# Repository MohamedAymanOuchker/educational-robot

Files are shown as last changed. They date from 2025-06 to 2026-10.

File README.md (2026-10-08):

# Educational Robot

> **P1 development revision:** the app/firmware control path now targets the confirmed 28BYJ-48 + ULN2003 build. Use the [new wiring](hardware/wiring.md) and matching app/firmware together. Hardware validation, printable exports and research reconciliation remain open; see [P1 status and test results](docs/p1-status.md).

> **P2 update:** named local Save/Open, execution-based practice progress, Bluetooth-only connection controls and a matching five-level curriculum are implemented. See [P2 status, tests and remaining work](docs/p2-status.md).

> **Android packaging:** the selected release ID, upgraded build tools and private-signing workflow are documented in the [release guide](docs/android-release.md). Debug packages are labeled RoboCode (Test); physical acceptance and a signed distribution release remain open.

> **Physical build handoff:** use the corrected [assembly guide](docs/assembly-guide.md), [blank acceptance record](docs/hardware-acceptance.md) and [CAD inventory/export checklist](hardware/cad-release.md). CAD inspection awaits the owner's CATIA installation; no physical tests or exports are claimed complete.

An affordable educational robotics platform designed to teach programming concepts to children aged 7-12 through hands-on interaction with a physical robot (developed as part of my engineering final year project internship).

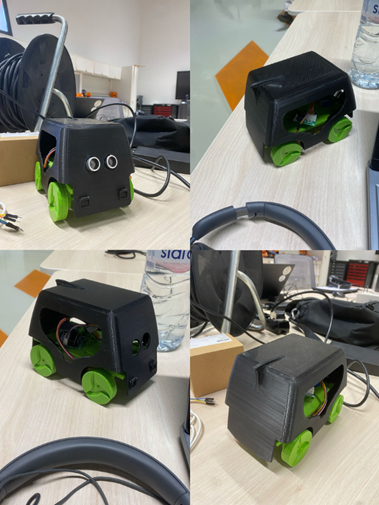
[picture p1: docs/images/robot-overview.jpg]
Robot Image







## 🎯 Project Overview

This prototype explores an affordable way to teach programming with a physical robot. The selected protected battery, regulator and external charger exceed the historical $40 parts estimate; see the [current parts selection and cost snapshot](hardware/power-system.md). A complete delivered build cost and comparative learning outcomes have not yet been established. The system combines:

- **ESP32-based hardware** with stepper motors and sensors
- **Flutter mobile app** with visual block programming
- **Progressive learning system** from basic commands to autonomous navigation
- **Real-time telemetry** for immediate feedback

## ✨ Key Features

- 📱 **Mobile-first design** - Flutter app with Android as the current build target
- 💰 **Cost-conscious design** - Documented parts selection; complete delivered costing pending
- 🎮 **Visual programming** - Custom block-based interface
- 🤖 **Auto Navigate** - Experimental three-second reactive activity
- 📊 **Real-time feedback** - Live sensor data visualization
- 💾 **Local programs** - Save/Open on the device; robot control uses Bluetooth
- 🔓 **Open source** - MIT license for educational use

## 🚀 Quick Start

### Prerequisites
- ESP32 development board
- 3D printer for chassis parts
- Compatible Android device with Bluetooth Low Energy for programming
- Basic soldering skills

### Hardware Assembly
1. Review the native CAD in `hardware/`; printable STL exports are still pending and `hardware/3d-models/` is not yet supplied
2. Follow the [Assembly Guide](docs/assembly-guide.md)
3. Use the [selected motor/power parts](hardware/power-system.md) and [revised ULN2003 wiring](hardware/wiring.md), then build/upload the modular firmware using PlatformIO

### Software Setup
1. Build the matching Android app from `mobile-app/` (see development instructions below)
2. Connect to the robot using the app's Bluetooth screen
3. Start with Level 1 programming challenges

## 📚 Documentation

- [**Assembly Guide**](docs/assembly-guide.md) - Step-by-step hardware build
- [**User Manual**](docs/user-manual.md) - How to use the system
- [**Curriculum Guide**](docs/curriculum-guide.md) - Educational activities
- [**Research & Evaluation**](docs/research-documentation.md) - Study results

## 🏗️ Project Structure

```
├── hardware/          # Native CATIA files and wiring guide; STL exports pending
├── firmware/          # ESP32 Arduino code (PlatformIO)
├── mobile-app/        # Flutter application
├── docs/              # All documentation, guides, and research
└── .github/           # CI/CD workflows
```

## 📋 Selected Bill of Materials

| Component | Quantity | Reference selection |
|---|---|---|
| ESP32 controller | 1 | ESP32-DevKitC V4 with WROOM module; verify any existing alternative board |
| 5 V motor + ULN2003 board | 2 kits | Olimex SM-5VDC-DRV, nominal 1:64 |
| Protected Li-ion battery | 1 | Tenergy 31003, 7.4 V / 2200 mAh |
| Fixed 5 V regulator | 1 | Pololu D24V22F5, item 2858 |
| External charger | 1 | Tenergy TLP-4000, item 01281 |
| HC-SR04 / MPU6050 | 1 each | Echo divider and 3.3 V-compatible IMU module |
| Power harness and protection | 1 set | DC fuse/switch, keyed connectors, insulated wiring and capacitors |
| Sensing dividers | 2 pairs | 2.2k/3.3k Echo; 20k/10k battery, 1% |
| Chassis, wheels and mounting hardware | 1 set | CAD/print fit and mechanical dimensions still require verification |

The [power-system specification](hardware/power-system.md) is the source for purchase links, ratings, the current budget and charging procedure. The four selected motor/power lines total **USD 67.43 plus EUR 5.00**, excluding the rest of this table, fabrication, tax and shipping. No complete-build price or measured runtime is claimed.

## 🎓 Educational Impact

The project documentation reports a pilot with 24 students aged 7-12. The author confirms that the study is real, but the aggregate results, session statistics and delayed follow-up claims require reconciliation against the original records. See [Research & Evaluation](docs/research-documentation.md) and the [reconciliation checklist](docs/research-reconciliation.md) before citing results. App progress indicators are not evidence of educational effectiveness.

## 🛠️ Development

### Building the Firmware
```bash
cd firmware/
# Using PlatformIO
pio run --target upload

# firmware/legacy is historical; it does not contain the current motor/safety fixes.
```

### Building the Mobile App
```bash
cd mobile-app/
# Tested toolchain: Flutter 3.41.4 / Dart 3.11.1
flutter pub get
flutter run
# To produce a local Android test package:
flutter build apk --debug
```

## 🤝 Contributing

We welcome contributions! Please see [CONTRIBUTING.md](CONTRIBUTING.md) for guidelines.

### Areas for Contribution
- [ ] iOS app development
- [ ] Additional language translations
- [ ] Curriculum expansion
- [ ] Hardware improvements
- [ ] Bug fixes and optimizations

## 📊 Performance Benchmarks

The following are historical reported figures. They have not been remeasured with this P1 motor/protocol revision and are not acceptance results for the updated code.

- **Movement Accuracy**: ±2cm per meter
- **Battery Life**: ~90 minutes continuous use
- **BLE Range**: 12+ meters
- **Command Latency**: <100ms
- **Setup Time**: 30 minutes average

## 🌍 Localization

The current app interface is English. Arabic localization is not implemented or validated in this build; translations into Arabic, French, Spanish and Portuguese are future contributions.

## 📄 License

This project is licensed under the MIT License - see the [LICENSE](LICENSE) file for details.

## 🙏 Acknowledgments

- **Euromed University of Fes** - Academic supervision
- **DICE/UM6P** - Host organization and support
- **Open source community** - Libraries and inspiration
- **Test participants** - Students and educators who provided feedback

## 📞 Contact

- **Author**: Mohamed Ayman OUCHKER
- **Email**: ayman.ouchker@outlook.com
- **Institution**: Euromed University of Fes
- **Project**: End of Studies Project 2024-2025

## 🌟 Star History

If this project helps you, please consider giving it a star! ⭐

---

**Made with ❤️ for democratizing robotics education**

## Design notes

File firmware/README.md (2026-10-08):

# E-Bug ESP32 firmware

The supported firmware is `src/`, built with PlatformIO for an ESP32 Dev Module. It controls two **28BYJ-48 motors through ULN2003 boards**. The archived `legacy/arduino_main/` sketch is historical reference and is not a supported firmware option for this release.

## Wiring and calibration

The old STEP/DIR wiring does not apply. Rewire each ULN2003 board in its marked IN1–IN4 order:

| Connection | ESP32 GPIOs |
|---|---|
| Left ULN2003 IN1, IN2, IN3, IN4 | 26, 27, 25, 33 |
| Right ULN2003 IN1, IN2, IN3, IN4 | 14, 13, 32, 23 |
| HC-SR04 trigger, echo | 5, 18 |
| MPU6050 SDA, SCL | 21, 22 |
| Battery divider ADC input | 35 |

See [the wiring guide](../hardware/wiring.md) and [selected motor/power parts](../hardware/power-system.md) before applying power. The reference design uses 5 V motors, a protected 2S Li-ion pack and a fixed 5 V regulator. Check existing parts against that selection. Share logic ground; reduce the HC-SR04 Echo voltage and verify the battery divider before connecting the ESP32. Firmware cannot select or verify the motor's physical voltage rating.

The driver uses an eight-phase half-step sequence, nominal **4096 half-steps per output revolution**, and **2000 microseconds per half-step** (500 half-steps/s, subject to RTOS scheduling). Gearbox variants differ: calibrate steps/revolution, the retained 65mm wheel diameter and 150mm track width against the actual robot. These geometry values are assumptions, not measured results.

The [physical acceptance record](../docs/hardware-acceptance.md#motion-calibration) provides calibration formulas and trial tables, including external gearing. Use the [assembly sequence](../docs/assembly-guide.md) to keep USB programming separate from powered motor tests. No runtime calibration command replaces those measurements.

`LEFT_MOTOR_INVERT=false` and `RIGHT_MOTOR_INVERT=true` assume mirrored mounting. Check forward, backward and both turns with wheels raised, and adjust these constants to match the wiring/mounting. Motors start deenergized and release their coils after each movement. STOP deenergizes all eight outputs and stays latched until a new explicit command is accepted. Old stored motor-speed settings are not loaded.

## Build, test and upload

Install PlatformIO Core, then run from this folder:

```sh
pio run
python test/host/run_tests.py
```

The host tests require Python and a C++17 compiler (`g++` or `clang++`, or set `CXX`). They compile the production source with hardware/FreeRTOS/BLE doubles. They check parsing, coils, cancellation races, queue capacity, sensor failures/freshness and navigation thresholds. They do not validate motor torque, actual radio delivery, power integrity or physical stopping distance.

The reproducible build pins Espressif32 7.0.1, ArduinoJson 6.21.6 and MPU6050 1.4.5. Only upload after checking the wiring and motor voltage:

```sh
pio run --target upload
pio device monitor
```

Serial monitoring uses 115200 baud. Board flashing is not part of the automated checks.

## BLE commands and results

The complete app/firmware contract is in [BLE protocol](../docs/ble-protocol.md). UUIDs remain unchanged. Send one ASCII command in one GATT write, with a request ID from 1 through 65535 and a trailing newline:

```text
1:F20
2:L90
3:STOP
```

| Command | Meaning |
|---|---|
| `F0` through `F500` | Forward distance in centimetres |
| `B0` through `B500` | Backward distance in centimetres |
| `L0` through `L360`, `R0` through `R360` | Turn angle in degrees |
| `STOP`, `AUTO_OFF` | Priority stop, cancel queue and leave autonomous mode |
| `AUTO_NAV` | Enable autonomous mode; completion confirms mode activation |
| `CLOOP_OFF` | Confirm the supported open-loop turning mode |
| `CALIBRATE`, `CLOOP_ON` | Explicit error: unavailable in this release |

Unnumbered commands are accepted for manual diagnostics and return ID 0. Runtime recalibration and closed-loop turns are not enabled. Initial IMU calibration may still run at boot if no calibration is stored; keep the robot still during startup.

Unknown commands, negative/fractional values, overflow, trailing garbage and overlong writes are rejected. They never become STOP or a clamped movement. Queue-full requests return errors. STOP bypasses the queue, cancels pending commands and prevents previously dequeued commands from rearming motion. Disconnection performs the same physical stop and queue cancellation; results cannot be delivered while disconnected.

All responses are newline-delimited JSON on the sensor notification characteristic. Records are split into chunks of at most 20 bytes; clients must buffer until newline. Complete records are serialized under a mutex so telemetry and command responses cannot interleave.

```json
{"type":"command","id":1,"status":"done"}
{"type":"command","id":2,"status":"cancelled","message":"stopped during command"}
{"type":"telemetry","distance":null,"distance_valid":false,"distance_age_ms":320,"battery":80,"heading":0,"temperature":25,"timestamp":10200}
```

An autonomous safety abort also emits `{"type":"fault","message":"..."}` so the app fails the active program even after mode activation was acknowledged. A user STOP alone does not emit a fault.

A blocked/aborted movement returns `error`/`cancelled`, never `done`. A failed movement also cancels the remaining queued program. `AUTO_NAV` runs until STOP/AUTO_OFF, disconnect or a sensing failure; the mobile app bounds its autonomous block to three seconds and then sends STOP.

## Sensing and remaining hardware checks

Ultrasonic sampling is scheduled every 60ms, with trigger spacing shared by all callers. No echo or out-of-range echo immediately invalidates the range. A successful sample older than 250ms is also invalid. Forward motion checks this coherent sensor snapshot at every half-step; missing/stale distance or a reading below 15cm stops the movement. Invalid range is reported as JSON `null`, never a false-clear 999cm value.

The sensor task services IMU integration nominally every 10ms (ultrasonic echo waits can delay it). Telemetry is sent separately every 250ms. Heading is an uncorrected gyro estimate and may drift; MPU6050 temperature is die temperature. Battery percentage depends on the configured pack/divider calibration.

Autonomous forward steps cover the previous 25–50cm dead zone. Invalid range or critically close obstacles stop autonomous operation. The existing turning/scanning heuristic remains experimental. There is no rear/side sensor: supervise backward movement and rotations. Bench validation must still establish motor direction, distance/angle calibration, reliable BLE stop/disconnect behavior, voltage levels, and stopping clearance on the actual robot.

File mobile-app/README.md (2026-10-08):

# RoboCode Mobile App

A Flutter-based mobile application for programming and controlling educational robots using visual block-based coding. This app is part of the Educational Robot project, designed to make robotics and programming accessible to learners.

The P1 revision requires the matching [firmware protocol](../docs/ble-protocol.md) and [28BYJ-48 / ULN2003 wiring](../hardware/wiring.md). Android is the current build target; iOS support and store releases are not validated.

## Features

- 🎯 Visual Block-Based Programming Interface
- 🤖 Bluetooth connectivity with educational robots
- 💾 Named local Save/Open with nested block and parameter restoration
- ✅ Five practice checks based on successful execution, separate from saving
- 📱 User-friendly interface with multiple screens:
  - Home Screen: Main navigation and project overview
  - Connect Screen: Bluetooth scan, connection and disconnection
  - Code Screen: Block-based programming interface
  - Sensors Screen: Automatically pushed readings with unavailable/stale states
- Run opens Robot Execution from Code; there is no placeholder Run tab

## Technical Stack

- **Framework**: Flutter
- **State Management**: Provider
- **Key Dependencies**:
  - `flutter_blue_plus`: Bluetooth communication
  - `flutter_inappwebview`: Web-based components
  - `provider`: State management
  - `shared_preferences`: Local data storage
  - `google_fonts`: Typography
  - `lottie`: Animations

## Getting Started

### Prerequisites

- Flutter 3.41.4 / Dart 3.11.1 (the validation and CI toolchain)
- Android SDK and a compatible Java installation (CI uses Java 17)
- Android device with Bluetooth Low Energy and the matching updated ESP32 firmware

Android packaging uses Gradle 8.14, Android Gradle Plugin 8.11.1 and Kotlin 2.2.20. See the [Android release guide](../docs/android-release.md) for the selected application ID, separate test installation, private signing setup and unsigned CI build checks. Normal release builds require an owner-provided key; debug signing is never used as a release fallback.

### Installation

1. Open the cloned project's app directory:
   ```bash
   cd educational-robot/mobile-app
   ```

2. Install dependencies:
   ```bash
   flutter pub get
   ```

3. Run the app:
   ```bash
   flutter run
   ```

### Development

Run the regression checks and create an Android test package:

```bash
flutter analyze --no-fatal-infos
flutter test
flutter build apk --debug
```

The tests cover protocol framing/completion, typed program execution and block editor behavior. Hardware connection, motor direction, stop latency and sensor behavior still require an actual robot. See [P1 status](../docs/p1-status.md) for validation results and open items.

Programs execute the edited block tree and wait for firmware completion records. Generated Dart is a preview only. If Distance uses fresh valid telemetry; its children are skipped when false. Auto Navigate runs for three seconds and stops. Leaving the execution screen or backgrounding the app cancels the run and requests STOP.

Use **Save** and **Open** in Code for a local library (up to 50 programs, 100 blocks each). Names are case-insensitive; replacement and clearing require confirmation. Unsaved edits survive tab switches, but must be saved before closing the app. No file export or cloud backup is implemented.

The connection UI supports **Bluetooth Low Energy only**. Scans filter for the robot service, report permission/adapter errors, stop after about ten seconds and cancel their native scan when the screen's subscription ends. The unused Wi-Fi UI, password form, service stubs, plugin and Wi-Fi permissions have been removed. Android permission behavior still needs physical-device testing.

The editor now reads a typed list of implemented blocks for each lesson. Home and Code use the same lesson names/descriptions; the [current curriculum](../docs/curriculum-guide.md) teaches explicit movement sequences, Wait, one-sided distance decisions and bounded Auto Navigate. Repeat/While, If/Else, speed controls, mapping, localization and iOS release support are not implemented.

Sensors automatically displays new telemetry. It clears missing/invalid fields and expired/disconnected readings instead of showing default values or carrying old readings into a new packet. Distance freshness includes the firmware's reported age. Battery is an estimate; IMU temperature and relative heading are not a room thermometer or compass. No monitoring Start/Stop buttons or movement controls appear in Sensors.

Practice checks are based on executed nonzero actions, conditional responses and successful final STOP. Save never awards progress. Old badge data retains lesson access without counting as verified execution; cached robot connection flags are ignored. See [P2 status](../docs/p2-status.md) for the storage format, migration, checks and remaining work.

The app is structured into several key directories:

- `lib/screens/`: Main application screens
- `lib/services/`: Business logic and state management
- `lib/widgets/`: Reusable UI components
  - `block_editor/`: Custom widgets for the visual programming interface

## Contributing

Please read the CONTRIBUTING.md file in the root directory for details on our code of conduct and the process for submitting pull requests.

## License

This project is licensed under the terms found in the LICENSE file in the root directory.

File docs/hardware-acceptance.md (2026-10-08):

# Physical robot acceptance record

Blank template prepared 8 October 2026. **All tests are NOT RUN until the tester records observations.** No phone, serial controller or physical robot was available for this documentation pass. CATIA validation/exports are deferred until the owner installs it.

Copy this file for each robot and test session. Use PASS, FAIL, NOT RUN or NOT APPLICABLE with a reason. A blank value is missing evidence, not zero or a pass. Keep this engineering record separate from participant/study data.

## Build identity

| Field | Recorded value |
| --- | --- |
| Robot / build ID | Pending |
| Tester and date | Pending |
| Git commit plus description of uncommitted changes | Pending |
| Firmware binary path + SHA-256 | Pending |
| App package path + SHA-256 / application ID / version | Pending |
| Phone model + Android version | Pending |
| ESP32 board/module revision | Pending |
| Delivered motor / driver labels, photos and polarity | Pending |
| Battery / regulator / charger model + condition | Pending |
| Harness connector, fuse, switch and wire identification | Pending |
| CAD assembly/revision + source hashes + export record | Pending |
| Mechanical dimensions / external gearing | Pending |
| Surface, payload and ambient conditions | Pending |
| Meter / timing / temperature instruments and resolution | Pending |

Use `Get-FileHash -Algorithm SHA256 -LiteralPath 'exact-file-path'` in PowerShell to identify a tested binary. A Git commit alone does not identify uncommitted firmware/configuration changes. Preserve the actual package and configuration used for each test.

## Acceptance limits agreed before testing

The power targets below come from the [project power specification](../hardware/power-system.md); they are not measured results. Record the remaining limits before judging a test. A successful protocol response is not proof of physical travel or stopping.

| Quantity | Target / decision required |
| --- | --- |
| Regulated 5 V rail | 4.8–5.2 V at specified test inputs/load and actual operation |
| Regulator test inputs / load | 8.4 V and 6.4 V input, 1.2 A output design load; use appropriate bench equipment |
| Battery operating procedure | Stop/recharge at about 6.4 V under load; no automatic firmware cutoff |
| Echo divider expected DC ratio | 3.3 / (2.2 + 3.3) = 0.6; approximately 3.0 V at 5.0 V input |
| Battery divider expected DC ratio | 10 / (20 + 10) = 1/3; approximately 2.8 V at 8.4 V input |
| Accessible-surface/component temperature limits | Record applicable component limits and an appropriate supervised-use limit before testing: pending |
| Explicit STOP maximum latency / extra travel | Pending; define for the intended test area and activity |
| BLE-loss maximum latency / extra travel | Pending; include radio loss-detection time, not only code response time |
| Linear error / repeatability at chosen distances | Pending |
| Left/right angular error / repeatability | Pending |
| Sensor error / repeatability at intended target distances | Pending |
| Required phone range and environmental conditions | Pending; no 12 m guarantee |

Without an agreed limit and measurement, record the result as NOT RUN or measured-but-not-accepted. Do not treat the absence of a failure message as acceptance.

## A. Mechanical and electrical preflight

Follow the [assembly guide](assembly-guide.md) and [wiring](../hardware/wiring.md). Wiring changes happen with power disconnected. Do not attach USB while the battery/external ESP32 5 V feed is connected.

| ID | Check | Measurement / evidence | Result |
| --- | --- | --- | --- |
| A1 | Native assembly opens; references resolved; part-to-file mapping complete | Pending | NOT RUN |
| A2 | Motor mounting, shaft/hub retention, gear ratio, free rotation and cable clearance | Pending | NOT RUN |
| A3 | Battery retention/removal, insulated terminals, fuse/switch/connector access | Pending | NOT RUN |
| A4 | Disconnected continuity, no supply short, ground/polarity/capacitor checks | Pending | NOT RUN |
| A5 | USB/external 5 V separation and actual ESP32 board pinout | Pending | NOT RUN |
| A6 | 8.4 V input, regulator unloaded and at 1.2 A design load | Pending | NOT RUN |
| A7 | 6.4 V input, regulator unloaded and at 1.2 A design load | Pending | NOT RUN |
| A8 | Battery divider before connection to GPIO35 | Pending | NOT RUN |
| A9 | Echo divider ratio and signal peak before connection to GPIO18 | Pending | NOT RUN |
| A10 | Actual idle/start/motion current, rail transients, fuse behavior | Pending | NOT RUN |
| A11 | Regulator, motor, driver, wiring and accessible-surface temperatures; test duration | Pending | NOT RUN |
| A12 | Charger/pack/harness match and external charging procedure | Pending | NOT RUN |

A multimeter DC reading alone does not measure transient rail droop or the peak of an Echo pulse. Record the instrument and any unmeasured behavior. Do not deliberately short a battery, defeat its protection or discharge it to emergency cutoff as a test.

## B. Stationary sensing and raised-wheel commissioning

Keep the chassis secured, wheels clear, hands away and the disconnect reachable. Restore/check wiring with power off between fault configurations. Use the app's short test programs described in the assembly guide.

| ID | Test | Observation / evidence | Result |
| --- | --- | --- | --- |
| B1 | Startup, connecting and reconnecting cause no uncommanded movement | Pending | NOT RUN |
| B2 | Forward/backward wheel directions and left/right turns agree with commands | Pending | NOT RUN |
| B3 | Single motion waits for completion; coils release after motion | Pending | NOT RUN |
| B4 | Stable front readings with measured targets at intended distances | Pending | NOT RUN |
| B5 | No echo / disconnected Echo signal reports unavailable and prevents forward motion | Pending | NOT RUN |
| B6 | Sensor fault during controlled forward motion stops/fails the action | Pending | NOT RUN |
| B7 | Battery estimate compared with meter; IMU temperature/relative heading interpreted correctly | Pending | NOT RUN |
| B8 | Physical disconnect stops powered drive; record any coasting | Pending | NOT RUN |

For B6, first agree a fault method that does not short or change energized wiring (for example a preinstalled insulated signal switch, or controlled loss of a valid acoustic target). Record the method and raw observation; do not label an arbitrary “far away” reading a guaranteed fault.

### Stop and cancellation observations

Begin with the wheels raised. Repeat relevant cases during short, controlled floor motion only after raised-wheel tests pass. Use video/timing equipment where needed. Record multiple trials, the maximum observed latency, extra wheel/chassis travel, and the app outcome. The reference point is the user action or fault onset, not receipt of a later log line.

| Trigger | Trials / conditions | Maximum measured latency | Extra travel / residual motion | App outcome; no restart on reconnect | Result |
| --- | --- | --- | --- | --- | --- |
| Whole-run Stop during a forward action | Pending | Pending | Pending | Pending | NOT RUN |
| Whole-run Stop during a turn | Pending | Pending | Pending | Pending | NOT RUN |
| Leave Robot Execution | Pending | Pending | Pending | Pending | NOT RUN |
| Background / lock phone | Pending | Pending | Pending | Pending | NOT RUN |
| Disconnect in Connect | Pending | Pending | Pending | Pending | NOT RUN |
| Disable phone Bluetooth / actual radio loss | Pending | Pending | Pending | Pending | NOT RUN |
| Ultrasonic invalid/stale condition during forward motion | Pending | Pending | Pending | Pending | NOT RUN |
| Auto Navigate timeout / fault | Pending | Pending | Pending | Pending | NOT RUN |

Differentiate a confirmed STOP, cancelled program, failed/unconfirmed STOP and disconnected robot. A UI status alone does not establish that physical motion ceased. Rear/side collision protection is not implemented.

## Motion calibration

Do this only after mechanical, power, sensor and stop checks pass. Constants are in `firmware/src/config.h`. The production formulas in `firmware/src/motor_control.cpp` are:

```text
linear half-steps = round(command_cm × 10 × STEPS_PER_REV / (pi × WHEEL_DIAMETER))
turn half-steps per wheel = round(ROBOT_WIDTH × abs(command_degrees) × STEPS_PER_REV
                                 / (360 × WHEEL_DIAMETER))
```

`STEPS_PER_REV` must represent effective half-steps per **wheel** revolution. If external gears exist, multiply motor-output half-steps/revolution by motor-output revolutions per wheel revolution. Verify tooth counts and physical motion; the nominal internal-gear value 4096 is not a measurement.

Record mechanical wheel diameter and centre-to-centre track width first. Resolve slipping, binding or missed steps before numerical correction. Repeat the same motion on the same surface and load; retain every trial, including failed/cancelled ones. Exclude failed motion from parameter fitting with a recorded reason.

| Trial | Command / direction | Actual distance (cm) or angle (degrees) | Surface / load / pack voltage | Completion / slip / notes |
| --- | --- | --- | --- | --- |
| 1 | Pending | Pending | Pending | Pending |
| 2 | Pending | Pending | Pending | Pending |
| 3 | Pending | Pending | Pending | Pending |
| 4 | Pending | Pending | Pending | Pending |
| 5 | Pending | Pending | Pending | Pending |

Copy the table for each distance and turn direction. Begin with 20 cm travel and 45° turns; increase to a longer baseline/90° only when clearance and the preceding checks permit.

For stable, nonzero travel measurements, adjust **one** linear parameter, not both at once:

```text
STEPS_PER_REV_new = STEPS_PER_REV_old × commanded_distance / mean_measured_distance
```

Alternatively, with independently established steps/revolution, use an effective rolling diameter:

```text
WHEEL_DIAMETER_new = WHEEL_DIAMETER_old × mean_measured_distance / commanded_distance
```

After linear calibration, an effective turn-track correction is:

```text
ROBOT_WIDTH_new = ROBOT_WIDTH_old × requested_turn_magnitude / mean_measured_turn_magnitude
```

These formulas follow the open-loop implementation; they are not measured results. Keep physical dimensions and fitted effective parameters separately identified. Round `STEPS_PER_REV` to a suitable integer. Do not average away a left/right discrepancy: inspect mechanics and record each direction's residual error. Rebuild/reflash and repeat tests after changes. Significant gearing/speed changes also require checking the app's command deadlines; a timeout must not be relabeled as successful completion.

| Parameter | Before | Measured basis / calculation | After | Retest evidence |
| --- | --- | --- | --- | --- |
| Effective half-steps / wheel revolution | Pending | Pending | Pending | Pending |
| Physical / effective wheel diameter (mm) | Pending | Pending | Pending | Pending |
| Physical / effective track width (mm) | Pending | Pending | Pending | Pending |
| Left/right inversion and step interval | Pending | Pending | Pending | Pending |

## C. Physical phone and lesson checks

| ID | Test | Phone / conditions / evidence | Result |
| --- | --- | --- | --- |
| C1 | First-run permission grant/denial/retry; Bluetooth off/on | Pending | NOT RUN |
| C2 | Scan finds the correct robot; stop/timeout/cancel; no late background scan | Pending | NOT RUN |
| C3 | Connect/reconnect after backgrounding and radio loss | Pending | NOT RUN |
| C4 | Sensors reflect fresh data; stale/missing/disconnected readings become Unavailable | Pending | NOT RUN |
| C5 | Short movement/Wait/nested true and false distance programs | Pending | NOT RUN |
| C6 | Save, app restart, Open, edit and supervised Run; no false practice badge | Pending | NOT RUN |
| C7 | False/invalid distance condition and aborted run report the right outcome | Pending | NOT RUN |
| C8 | Three-second Auto Navigate: actual trajectory, final heading, timeout/fault and stop behavior | Pending | NOT RUN |
| C9 | Portrait layout, large text, keyboard and system Back on intended phones | Pending | NOT RUN |
| C10 | Measured connection time/range with stated environment and radio-loss response | Pending | NOT RUN |

Auto Navigate may stop during a scan/turn; it does not promise a completed route or return to its original heading. Sensor validity is not clearance behind or beside the robot. A successful practice badge is not a study outcome.

## Decision and unresolved work

| Field | Recorded value |
| --- | --- |
| Failed / unmeasured items and corrective actions | Pending |
| Retest references after fixes | Pending |
| Permitted supervised activity and operating limits | Pending |
| Reviewer / date | Pending |
| Overall decision | NOT ACCEPTED — template is unfilled |

Do not convert NOT RUN to PASS to close the project. Keep native/exported CAD evidence, physical test evidence, Android signing/distribution and [research reconciliation](research-reconciliation.md) as separate deliverables. None is established by filling in another.

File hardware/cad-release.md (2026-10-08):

# CAD inventory and mechanical release

Status on 8 October 2026: **native files inventoried; geometry and assembly references not validated; no printable or neutral exports supplied**. The owner will install CATIA later. Native files have been preserved without renaming or deletion.

## What is present

[cad-inventory.json](cad-inventory.json) records exact relative paths, file sizes and SHA-256 hashes for **10 CATPart files and 4 CATProduct files**. Hashes identify these file versions; they do not verify dimensions, manufacturability or assembly completeness.

| Native file | Bytes | Role in the robot |
| --- | ---: | --- |
| `jh.CATPart` | 553637 | Unverified |
| `Part1.CATPart` | 367475 | Unverified |
| `Part2.CATPart` | 171317 | Unverified |
| `Part3 (1).CATPart` | 83476 | Unverified; byte-identical to Part3 |
| `Part3.CATPart` | 83476 | Unverified; byte-identical to Part3 (1) |
| `Part4.CATPart` | 194926 | Unverified |
| `Part6.CATPart` | 227954 | Unverified |
| `StepperMotor.CATPart` | 78186 | Name suggests a motor model; compatibility with delivered motor unverified |
| `Zoo Text-to-CAD_1.CATPart` | 343300 | Unverified |
| `Zoo Text-to-CAD_2.CATPart` | 321603 | Unverified |
| `Product1 1.CATProduct` | 80326 | Candidate assembly; hierarchy unverified |
| `Product1.CATProduct` | 79714 | Candidate assembly; hierarchy unverified |
| `Product3.CATProduct` | 28491 | Candidate assembly; hierarchy unverified |
| `miter-gear-and-driver-gear-to-drive-it-make-the-driver-gear-one-half-size-of-the-miter-gear (1).CATProduct` | 15896 | Name suggests gears; actual ratio and placement unverified |

Do not delete either Part3 copy until CATIA shows which paths the assemblies reference. File identity does not establish that either filename is unused. Likewise, similar product names do not establish which assembly is final. A filename describing a gear ratio is not a dimensional measurement.

## Work to complete when CATIA is available

1. Open each candidate CATProduct from this folder. Record the CATIA version, missing references, load/update warnings and resolved child paths. Select the actual top-level robot assembly using its contents and the intended physical build.
2. Identify each printable part and each purchased/reference component. Record quantities, mirrored variants, suppressed components and dependencies. Map descriptive part names to existing files before considering native-file renames.
3. Verify dimensions in millimetres: delivered motor mounting and shaft profile, wheel/hub fit, external gear tooth counts and alignment, battery retention/removal, PCB mounting, switch access, wire clearance and sensor sight line. Use [selected parts](power-system.md), with actual measurements taking precedence over provisional envelopes.
4. Check clashes, fastener engagement, wall thickness, free wheel/gear motion and assembly access. Record tolerances and intended fabrication method. Do not infer clearances from screenshots.
5. Export the verified printable parts to STL and suitable neutral geometry to STEP. Record units, source revision, export settings and part quantity. These formats are deliverables to create, not files already present.
6. Reopen exports in an independent viewer/slicer. Confirm scale against a known measured feature, dimensions, orientation and mesh suitability. Slice a critical fit piece first and record the printer/material/settings and result.
7. Supply an assembly drawing or annotated views showing how part names, fasteners and electrical components correspond to the actual design. Complete the mapping below and update the inventory for intentionally revised native files, retaining the prior inventory with the build evidence.

## Part-to-file and export record

The names below describe functions to identify. They do not assert that a matching part exists in the current assembly. Add or remove rows after inspecting the real design.

| Function | Native source + assembly instance | Quantity | Measured critical dimensions / fit | STL / STEP / drawing paths | Verification evidence |
| --- | --- | --- | --- | --- | --- |
| Chassis / structural base | Pending | Pending | Pending | Not supplied | Not checked |
| Motor mounts | Pending | Pending | Delivered mounting holes and shaft access | Not supplied | Not checked |
| Wheel hubs / wheels | Pending | Pending | Shaft profile, diameter, retention | Not supplied | Not checked |
| External gears, if actually used | Pending | Pending | Tooth counts, ratio, alignment | Not supplied | Not checked |
| Battery holder / retention | Pending | Pending | Delivered pack + harness/removal clearance | Not supplied | Not checked |
| Ultrasonic / IMU mount | Pending | Pending | Sensor orientation and sight line | Not supplied | Not checked |
| Electronics mounting / cover, if used | Pending | Pending | PCB spacing, access, insulation | Not supplied | Not checked |

For each export, keep its hash and the native source hash from the inventory. Record any repair or unit conversion. A successful export alone is not a passed physical fit test.

Continue with the [assembly guide](../docs/assembly-guide.md) and [hardware acceptance record](../docs/hardware-acceptance.md) once the necessary geometry and parts are ready.

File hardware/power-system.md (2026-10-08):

# Selected motor and power system

Design selection: 8 October 2026. The owner authorized choosing a complete compatible setup. These are the parts to build toward; online research does not identify the parts already installed. The assembly still needs inspection and bench testing.

## Selected parts

| Item | Qty | Selected part | Reason / specification |
|---|---:|---|---|
| Motor and driver | 2 | [Olimex SM-5VDC-DRV](https://www.olimex.com/Products/Robot-CNC-Parts/StepperMotors/SM-5VDC-DRV/) | 5 V 28BYJ-48, nominal 1:64 gearing, ULN2003 board; matches the current four-input-per-motor firmware |
| Battery | 1 | [Tenergy 31003](https://power.tenergy.com/tenergy-li-ion-7-4v-2200mah-rechargeable-battery-w-pcb-2s1p-16-25wh-4a-rate/) | Factory-assembled, PCB-protected 2S1P Li-ion pack, 7.4 V nominal, 2200 mAh |
| Regulator | 1 | [Pololu D24V22F5, item 2858](https://www.pololu.com/product/2858) | Fixed 5 V buck regulator; manufacturer lists 2.5 A typical maximum at 24 V input, with actual capacity depending on input and cooling |
| External charger | 1 | [Tenergy TLP-4000, 01281](https://power.tenergy.com/tenergy-tlp-4000-universal-1a-smart-charger-for-li-ion-polymer-battery-pack-3-7v-14-8v-1-4-cell/) | 1 A CC/CV charger, explicitly listed by Tenergy for battery 31003; automatically recognizes supported cell counts |

Use two matching 5 V motors. Existing units may be retained only after their labels, wiring and gearing are checked. A ULN2003 board marked "5–12 V" does not change the attached motor's voltage rating. Do not apply the battery directly to the motor supply.

The chosen pack uses **8.4 V at full charge and 6.0 V as its specified discharge endpoint**. The existing firmware constants (8.4 / 6.0 V and a divide-by-three sensing network) already match those endpoints. The older [manufacturer specification, page 3](https://www.tenergy.com/core/media/media.nl/id.36145/c.671216/.f?h=384b24cc1d4ad2a6829c) confirms them. Battery percentage remains an approximate voltage-based indication, not protection or an automatic shutdown.

Source discrepancies are recorded instead of silently selecting the larger rating: the current battery page shows both 3 A and 4 A discharge figures, so use **3 A as the design ceiling**. The older sheet and current listing also differ on physical dimensions; measure the delivered pack before finalizing its holder.

## Additional assembly parts

These are project design choices, subject to the load and wiring checks below:

- **F1:** 2 A fast-acting fuse with a documented DC rating of at least 32 V, in an insulated holder close to the battery's positive output. Use a fuse/holder suitable for a lithium battery's possible fault current; the pack PCB does not replace it.
- **S1:** accessible on/off switch rated at least 3 A at 12 V DC. An AC-only switch rating is not sufficient evidence of its DC rating.
- **J1:** keyed, locking two-pin battery connector/harness rated at least 3 A at 12 V DC, with recessed battery-side contacts. Specify pin 1 as positive/red and pin 2 as negative/black on both the robot and charger adapter; verify polarity electrically.
- Short **20 AWG stranded copper** power leads, insulated joints, strain relief and a soldered/terminal-block distribution point. Keep motor current out of solderless breadboard rails and thin signal jumpers.
- **C1:** 470 microfarad, 16 V electrolytic across the 5 V distribution rail, observing polarity; 100 nF ceramic locally across each driver's supply.
- Echo divider: **2.2 kohm / 3.3 kohm, 1%**. Battery divider: **20 kohm / 10 kohm, 1%**. See the [GPIO wiring guide](wiring.md).
- Insulated regulator mounting, battery retention and a charger mains lead/plug suitable for the local socket. Do not open or modify mains-side equipment.

The standard battery is supplied with bare leads and the charger with clips: **the parts do not arrive as a plug-and-play harness**. Have the pack supplier or a competent assembler fit J1 and an insulated matching charger adapter. Work on the provided leads, never directly on the cells. Exposed clip connections are not the student operating interface.

## Power connections

```text
Tenergy 31003 protected pack
  P+ -- F1 (2 A) -- J1 pin 1 -- S1 --+-- Pololu VIN
                                   +-- 20k/10k divider -- GPIO35
  P- -------------- J1 pin 2 -------+-- common GND

Pololu VOUT (5 V) --+-- left ULN2003 motor supply
                   +-- right ULN2003 motor supply
                   +-- HC-SR04 VCC
                   +-- removable feed --> ESP32 board 5V input
                   +-- C1 positive; C1 negative --> GND

ESP32 board 3V3 ---------------------- MPU6050 supply (3.3 V-compatible module)
All board/driver/sensor grounds ------ common GND

Charging: unplug J1 from the robot and connect the fused pack harness
          to the matching TLP-4000 adapter instead. No simultaneous load.
```

Use the regulator's labeled **VIN, GND and VOUT**. Leave **EN and PG unconnected** in this design; EN has an onboard pull-up. Do not connect EN to an ESP32 GPIO directly. Its fixed output needs no potentiometer adjustment. The regulator's dropout, thermal and current limits must be verified at the actual load. [Pololu connection instructions](https://www.pololu.com/product/2858).

The controller reference is an **ESP32-DevKitC V4 with an ESP32-WROOM module**. Feed its 5V header, never a bare WROOM module's 3.3 V supply. Espressif requires choosing only one board power source. For USB programming, unplug the battery and remove the board's external 5 V feed so USB cannot backfeed the regulator/motor rail. Disconnect USB before restoring battery operation. An existing different ESP32 board needs its own pinout checked. [Espressif board power instructions](https://docs.espressif.com/projects/esp-dev-kits/en/latest/esp32/esp32-devkitc/user_guide.html).

## Current budget and operating limits

This is a **calculated design allowance**, not a measurement or battery-life claim:

| 5 V rail load | Allowance |
|---|---:|
| Both motors, up to two energized coils each | 0.45 A |
| ESP32 development board, including radio activity | 0.55 A |
| Sensors and driver indicator LEDs | 0.10 A |
| Reserve | 0.10 A |
| **Design test load** | **1.20 A / 6 W** |

The motor estimate uses the 50 ohm +/-10% winding example in [Waveshare's 28BYJ-48 documentation](https://files.waveshare.com/upload/f/f8/Motor_Control_Shield_User_Manual_EN.pdf): four active coils at 5 V / 45 ohm give approximately 0.44 A before driver losses. That is an assumption until the selected motors are measured. The controller allowance accounts for [Espressif's recommendation of at least 500 mA supply capability](https://docs.espressif.com/projects/esp-hardware-design-guidelines/en/latest/esp32/schematic-checklist.html), not a claim that the board continuously draws that current.

At 6.4 V input, 6 W output and an assumed 85% conversion efficiency, estimated battery current is `6 / (6.4 * 0.85) = 1.10 A`. This is below the conservative pack limit and leaves room below F1's nominal rating. Validate startup inrush and fuse suitability; do not increase the fuse simply to hide an unexplained trip.

For supervised use, stop and recharge at about **6.4 V under load**, before the specified 6.0 V endpoint. This is an operating target, not a firmware cutoff. Verify voltage with a meter while calibrating telemetry; do not intentionally run to the pack's emergency PCB cutoff. Keep the power switch off during storage. Actual runtime and loaded motor torque remain unmeasured.

## Charging procedure

1. An adult switches the robot off, unplugs J1 and removes the pack for charging. The fuse stays with the pack harness.
2. Check the pack and keyed adapter, then use the selected TLP-4000 according to its instructions. It accepts 100–240 V AC and charges this protected 2S pack at up to 1 A; charge indoors within the pack's permitted temperature range.
3. Charge attended, clear of combustible materials. Disconnect after the charger's completion indication. Reconnect to the robot only after removing the charger.

This charger is specified for **protected** Li-ion/LiPo packs; it is not a balance charger for unprotected hobby packs. Do not substitute a TP4056 single-cell board or an ordinary DC adapter. No onboard charging is part of this design. [Tenergy charger requirements](https://power.tenergy.com/tenergy-tlp-4000-universal-1a-smart-charger-for-li-ion-polymer-battery-pack-3-7v-14-8v-1-4-cell/).

## Mechanical checks and acceptance

- The selected motor kit lists **35 mm mounting-hole spacing**, with M4 mounting holes. The previous assembly guide confused the 28 mm motor diameter with hole spacing. Verify the delivered parts, shaft/hub fit and CAD; select screw length after measuring the bracket.
- Reserve roughly **75 x 40 x 25 mm plus connector, wire-bend and retention space** for the battery as a preliminary envelope. This allowance is not a verified CAD fit.
- Before connecting the ESP32, measure the regulator rail and both divider outputs. At 8.4 V battery input, the battery divider should produce approximately 2.8 V; a 5 V Echo should produce approximately 3.0 V.
- Check the fixed regulator remains within **4.8–5.2 V** at 8.4 V and 6.4 V input under the 1.2 A design test load, with no sustained thermal shutdown, loose contacts or unsafe accessible surfaces. Check transients during real motor starts as well.
- With wheels raised, verify both directions, STOP, Bluetooth loss and sensor-failure behavior. Only then perform supervised floor tests and distance/turn calibration.

Record the delivered part numbers, motor labels, measured voltages/current/temperature and results in a copy of the [hardware acceptance record](../docs/hardware-acceptance.md) before marking hardware acceptance complete. Use the [CAD release checklist](cad-release.md) to reconcile mounts and the holder with the actual geometry. Firmware cannot prove the voltage printed on a physical motor or certify its power wiring.

## Cost and availability snapshot

Manufacturer listings checked 8 October 2026: two Olimex kits **EUR 5.00 total**, battery **USD 18.49**, regulator **USD 18.95**, charger **USD 29.99**. The three power items total **USD 67.43**, before motors, wiring, protection accessories, controller, sensors, fabrication, tax, shipping or import charges. The charger is reusable lab equipment. These selections replace the old incomplete USD 40 project estimate; they are not a local delivered quote. Pololu's direct listing showed backorders; confirm distributor stock before purchasing. Nothing has been ordered.

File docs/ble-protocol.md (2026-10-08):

# Robot command protocol (P1 revision)

Use the matching updated app and firmware together. The service/characteristic UUIDs remain unchanged; old apps that send `FORWARD:100` or `GET_SENSORS` are not compatible with this protocol.

- Service: `12345678-1234-1234-1234-123456789abc`
- Write command: `12345678-1234-1234-1234-123456789abd`
- Notify records: `12345678-1234-1234-1234-123456789abe`

## Commands

A request is ASCII `<id>:<command>\n`, with an integer ID from 1 to 65535. Keep IDs unique for pending requests. A BLE write acknowledgement only confirms transport; wait for the matching completion record before continuing a program.

| Command | Meaning |
|---|---|
| `F0` .. `F500` | Move forward by an integer number of centimetres |
| `B0` .. `B500` | Move backward by an integer number of centimetres |
| `L0` .. `L360` | Turn left by an integer number of degrees |
| `R0` .. `R360` | Turn right by an integer number of degrees |
| `STOP` | Interrupt motion, release coils, cancel queued commands and disable autonomy |
| `AUTO_NAV` | Enable reactive obstacle avoidance; completion means mode was enabled |
| `AUTO_OFF` | Disable autonomous motion and stop |
| `CALIBRATE` | Currently rejected; runtime calibration is not validated in this revision |
| `CLOOP_ON` | Currently rejected; experimental closed-loop turning is unavailable |
| `CLOOP_OFF` | Keep open-loop calibrated half-step turning |

Zero-valued movements are no-ops. Reject malformed, negative, fractional and out-of-range parameters instead of silently clamping them. Unknown commands return an error; they must not become STOP. Optional unnumbered commands are reserved for manual diagnostic clients; the app always uses IDs.

Example request: `42:F20\n`.

## Notifications

All notifications form a stream of UTF-8 JSON records, each terminated by a real newline. A record may span several notifications, and a receiver must not assume one notification equals one record. The firmware uses chunks of at most 20 bytes to fit the baseline ATT notification payload and serializes records to prevent telemetry/completion fragments from interleaving.

Buffer bytes until newline, decode the complete record, then parse JSON. Bound the receive buffer and handle malformed records without reporting success.

Command completion example:

```json
{"type":"command","id":42,"status":"done"}
```

`status` is `done`, `error`, or `cancelled`. An optional `message` explains rejection, sensor failure, obstacle interruption or cancellation. A blocked/aborted move must not report `done`. Queue overflow is an error. STOP is processed ahead of queued motion, and requests received before STOP cannot rearm motion afterward. A new explicit request after stopping can rearm; reconnecting alone cannot.

An autonomous safety abort stops the robot and sends a separate fault record, since the earlier `AUTO_NAV` completion only acknowledged enabling the mode:

```json
{"type":"fault","message":"autonomous distance unavailable or stale"}
```

The app aborts an active program on a fault, requests STOP, and reports failure. A deliberate user STOP does not generate a fault. Fault records use the same newline framing and serialized notification stream as other records.

Telemetry example (illustrative, not a measurement):

```json
{"type":"telemetry","distance":30.0,"distance_valid":true,"distance_age_ms":20,"battery":80.0,"heading":10.0,"temperature":25.0,"timestamp":1234}
```

Invalid distance is represented by `distance_valid:false` and a null distance. The client considers both firmware measurement age and local time since reception; a stale observation is not a clear path. `timestamp` is device uptime, not wall-clock time. Status/heartbeat/command records must not overwrite the last telemetry snapshot.

Each telemetry record replaces the prior sample atomically, including optional battery, temperature and heading fields. A missing field cannot inherit an old value with a refreshed receipt time. The current Sensors display uses a 500 ms freshness limit, checks expiry every 250 ms, and clears values on disconnect. Distance age includes `distance_age_ms`; other displayed fields use receipt age. These display checks do not replace the executor's freshness check when it evaluates a condition.

There are no `GET_SENSORS`, `GET_DISTANCE`, `SET_SPEED` or Dart-source commands. The app uses pushed telemetry. The app's Auto Navigate block runs a bounded three-second activity and then stops; it does not treat enabling an indefinite autonomous mode as a completed route.

The app starts command deadlines before transport writes and never treats a write acknowledgement as motion completion. A STOP without a matching successful response stays unconfirmed: the app attempts to disconnect BLE to trigger the firmware's disconnect stop, then waits for old native writes to finish before allowing a reconnect. It does not report a confirmed physical stop just because it requested disconnection. Actual radio loss detection and stop latency require hardware testing.

## Required checks

- Valid motion and a matching completion; no early completion on BLE write success.
- Fragmented/multiple/malformed records and unrelated command IDs.
- True and false distance conditions, including missing/stale measurements.
- STOP during motion, with pending work and a full queue; no old command resumes.
- Device disconnect, app backgrounding and leaving the run view stop/cancel execution.
- Invalid command/range, queue overflow, sensor timeout and blocked movement return failure rather than success.

Open-loop completion means the requested motor sequence finished; there is no wheel encoder verifying physical displacement. Check direction, calibration and stopping behavior on the actual robot. The front sensor cannot detect rear/side hazards.

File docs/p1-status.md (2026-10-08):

# P1 finalization status

Development revision: 8 October 2026. This file records what has been fixed and what still needs evidence; it is not a hardware sign-off.

## Software work

The current P1 change aligns the mobile app and firmware through [numbered commands and completion records](ble-protocol.md), replaces generated-text execution with typed block execution, fixes parameter editing/nesting, and introduces stop/disconnect cancellation and sensor validity checks. Autonomous safety faults now fail the active app program instead of appearing successful after its timer expires.

The motor implementation now targets the owner's confirmed **28BYJ-48 + ULN2003** hardware. It requires the [new eight-input wiring](../hardware/wiring.md), nominal half-step calibration and physical direction checks. The old STEP/DIR wiring and archived Arduino sketch do not apply to this revision.

## Validation

- **Firmware host regression suite: passed, 903 assertions.** Production firmware is compiled against test doubles for GPIO, sensors, BLE and RTOS facilities. Checks cover strict parsing/ranges, left/right coil sequences, STOP during motion, queue overflow, cancellation of already dequeued work, disconnect, failed/stale sensing, the 25–50cm navigation range, safety faults and concurrent notification producers. Run `python firmware/test/host/run_tests.py` with a C++17 compiler available.
- **ESP32 PlatformIO build: passed.** PlatformIO 6.1.18, Espressif32 7.0.1, ArduinoJson 6.21.6 and MPU6050 1.4.5. RAM usage: 39,972 / 327,680 bytes; flash usage: 1,190,949 / 1,310,720 bytes. This verifies compilation, not a flashed or measured robot.
- **Flutter regression suite: passed, 38 tests.** Covers mutable block parameters, editing limits, nesting/reparenting, independent program snapshots, true/false conditions, completion ordering, malformed/fragmented notifications, stale/incomplete telemetry, autonomous faults, failed writes, command deadlines, STOP retry, unconfirmed STOP disconnection, route exit, backgrounding and disposal. Uses simulated transport/robot clients; it does not validate Android Bluetooth on a physical phone.
- **Flutter analysis: passed with `--no-fatal-infos`.** No errors or warnings; 217 informational lints remain. Toolchain: Flutter 3.41.4 / Dart 3.11.1.
- **Android debug APK: built successfully** from the final app source with `flutter build apk --debug --no-pub`. Local output: `mobile-app/build/app/outputs/flutter-apk/app-debug.apk`. The incremental final build completed in 71.9 seconds. It is a debug-signed test package and has not been installed or tested against a physical robot in this pass.

CI now runs the firmware host suite/build and the app analysis/tests/Android debug build. App failures are no longer ignored. The workflow itself has not been run remotely in this change. Informational style lints are allowed; errors and warnings fail analysis. Kotlin 1.8.22 produced a future-support warning at this checkpoint; the subsequent [P2 toolchain update](p2-status.md#completed-android-release-preparation) resolves it. Release signing/store distribution and iOS builds remain outside this P1 validation.

Runtime `CALIBRATE` and `CLOOP_ON` explicitly return errors while unvalidated. Open-loop motion completion means the requested coil sequence finished, not that wheel displacement was independently measured. The front sensor does not protect the robot's rear or sides. Auto Navigate is an experimental reactive behavior bounded to three seconds by the app; no-path recovery now stops instead of reversing blindly.

## Items requiring the physical build or original records

**Motor and power selection is complete:** the owner authorized choosing the parts, and the [reference power system](../hardware/power-system.md) now records exact motor, battery, regulator and charger models, sources, a current budget, fuse/harness requirements and charging instructions. Existing firmware voltage endpoints match the chosen pack; only explanatory comments changed. This closes the selection decision, not the physical acceptance checks below.

- **Hardware acceptance remains open:** obtain or verify parts against the selected models, assemble the fused harness, check eight-input wiring, supply and divider voltages, motor directions, mechanical ratios, wheel dimensions, stop latency and sensor-failure behavior. No robot was attached during code development. The selected motor mounting pattern must be reconciled with the CAD before printing.
- **Printable hardware remains open:** the [CAD inventory and release checklist](../hardware/cad-release.md) now identify 10 native parts and 4 assemblies by filename, size and hash. The two Part3 files are byte-identical and retained pending reference checks. The owner will install CATIA later; geometry, STL/neutral exports, tolerances and assembled part/gear mapping remain unverified. Export from the actual validated design rather than inventing replacement geometry.
- **Research reconciliation remains open:** the study is author-confirmed as real, but the supplied paper folder contains aggregates rather than the original analysis records needed to resolve contradictions. See [the reconciliation checklist](research-reconciliation.md). Existing results have not been replaced with guessed numbers.

Do not label the entire project finalized until these open items are completed. Program persistence and practice progress are now addressed in the [P2 update](p2-status.md); expanded curriculum/loops, iOS release support and other P2 work remain separate from this P1 pass. The validation figures above record the P1 checkpoint; the P2 status records subsequent app validation.

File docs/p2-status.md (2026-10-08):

# P2 finalization status

Development revision: 8 October 2026. This update addresses the original audit's P2 findings 10 (saving/progress), 11 (current feature scope), the app scan/display lifecycle in 12, and the operating-guide portion of 15. It does not close the physical-build, CAD-export or research-record requirements in [P1 status](p1-status.md).

## Completed: local programs and truthful practice progress

- **Save/Open:** the Code screen now stores named programs on the device, including lesson, save time, block parameters, positions, colors and nested children. Opening creates independent editable blocks with rebuilt parent links. A new name keeps a separate copy; replacement uses case-insensitive names and asks for confirmation.
- **Workspace protection:** Open asks before replacing unsaved changes, Clear asks before removing blocks, and switching tabs retains the workspace. Saved programs remain available after clearing or recreating the editor. Closing the app still requires an explicit Save; autosave, file export and cloud backup are not implemented.
- **Storage failures:** failed writes do not show a successful Save or award practice progress. Unsupported or malformed stored data is reported and retained rather than silently reset. Concurrent program saves are serialized. The library is limited to 50 programs of at most 100 blocks each, with names of 1–64 characters.
- **Practice checks:** Save no longer awards lesson completion. The executor records the actions actually completed during a successful run; skipped branches, zero-valued movement/waits, failures, cancellation and an unconfirmed final STOP do not qualify. Sensor lessons require an executed response inside a true condition. See the [user manual](user-manual.md#practice-levels) for all five requirements.
- **Accurate progress:** the progress bar now starts at 0% and reaches exactly 100% for five checks. Completion refers to the lesson captured when the run starts. The editor does not advance itself during completion; the next lesson is selected on Home. Existing lesson access is preserved during migration, while old presence-only badges do not count as executed practice.
- **Live connection status:** connection flags are no longer persisted or restored from disk. The home page cancels its connection subscription when disposed. Removed the unused competing `ProgressService` so the app has one progress store.

Practice checks establish that the app observed successful command completion. They do not measure actual wheel displacement, path accuracy, obstacle clearance or student learning. The teacher's assessment and physical acceptance tests remain necessary.

## Completed: feature scope, discovery and telemetry display

- **Four useful tabs:** Home, Connect, Code and Sensors. Robot Execution opens from Run in Code; the empty Run tab was removed. The connection screen offers Bluetooth only. Wi-Fi scanning, password entry, connection stubs, the unused `wifi_iot` dependency and Wi-Fi permissions were removed. The Android manifest now declares BLE as required.
- **Owned scan lifecycle:** discovery filters on the advertised robot service UUID, reports permission/adapter errors instead of returning a misleading empty result, and ends after a bounded scan. Native results, timers and subscriptions are cleaned up on completion/cancellation. Cancelling during permission work prevents a late scan from starting; cancelling pending native startup waits for startup then requests stop. These paths are simulated in tests; phone permission behavior and radio timing remain physical-device checks.
- **One lesson definition:** the editor uses typed `BlockType` lists rather than historical Blockly XML. Home and Code share the names and descriptions. Only movement/Stop, Wait, If Distance and Auto Navigate appear, at their respective levels; there are no unused loop, Else, math or path-planning definitions in the active toolbox.
- **Honest sensor display:** readings arrive automatically without pretend monitoring Start/Stop buttons. No sample, a missing/invalid field, disconnect or stale telemetry shows Unavailable. New telemetry replaces the prior packet rather than refreshing old optional fields. Distance includes firmware age and reception age; display expiry is checked every 250 ms against a 500 ms limit. The dashboard no longer labels a single front reading as “All Clear.” Battery, chip temperature and relative heading are described with their actual limitations.
- **Current guides:** the [manual](user-manual.md) and [curriculum](curriculum-guide.md) describe the implemented five-level sequence and distinguish single distance checks, normal Stop blocks, whole-run Stop, and bounded autonomy. Earlier versions are preserved under [docs/archive](archive/) with rebased links and a historical-status notice. Original reported research figures were retained there and remain subject to reconciliation. The README no longer claims implemented Arabic localization.

## Completed: Android release preparation

- **Compatible build tools:** Gradle 8.14, Android Gradle Plugin 8.11.1 and Kotlin 2.2.20 match the pinned Flutter SDK's Android template defaults. The Gradle download has a pinned checksum; Java/Kotlin bytecode targets are aligned at 17. The prior Kotlin future-support warning is resolved.
- **Selected identity:** the owner selected `io.github.mohamedaymanouchker.robocode`. Namespace, activity package and manifest agree. Debug builds have a `.debug` ID and RoboCode (Test) label; profile builds use `.profile`. Old `com.example.robocode` data stays in its separate installation; there is no automatic migration.
- **Private release signing:** normal release builds require local `android/key.properties` and an owner-provided keystore. The old debug-signing fallback was removed. A blank example and [release instructions](android-release.md) are included; no permanent key or passwords were generated. Explicit unsigned mode permits compilation checks while ignoring private signing configuration.
- **Package checks in CI:** the workflow now checks missing-signing rejection, compiles unsigned release APK/AAB packages, inspects their identities/permissions/signing states and retains only the debug test APK. These workflow changes have not been run remotely.

## Completed: assembly and physical-test handoff

- **Current assembly procedure:** the guide now follows the selected power/wiring revision, separates USB-only programming from battery-powered motor tests, and requires measured geometry before printing. Unsupported print times/settings, assumed shaft fit, a fixed "optimal" sensor angle, Bluetooth range/connection guarantees and a canned success log were removed from active instructions. The earlier guide is preserved in [the archive](archive/assembly-guide.md).
- **CAD inventory:** [14 native files](../hardware/cad-release.md) have recorded sizes and SHA-256 hashes, including the byte-identical Part3 pair. No native file was renamed, removed or converted. The owner will install CATIA later; the assembly hierarchy, actual component fit and printable/neutral exports remain pending.
- **Physical test record:** a [blank acceptance record](hardware-acceptance.md) now covers build identity, power measurements, raised-wheel commissioning, stopping/fault behavior, phone checks and calibration formulas derived from the firmware. Every physical test remains NOT RUN. No Android device or serial controller was detected during the local connection check; no installation, flashing or motion test was performed.

## Storage and migration

`ProgramStore` uses the `savedPrograms.v1` SharedPreferences key containing a JSON object with `version: 1` and a `programs` list. Each entry contains `name`, `level`, `savedAt` (UTC) and `blocks`. Block types use stable enum names, parameters use their documented units, and children retain their array order. Parent references are reconstructed rather than serialized. Unknown block types, invalid parameters/positions, leaf children, duplicate names and excessive block counts are rejected.

`AppState` uses `practiceProgress.v1` with `version`, `currentLevel`, `completedLevels` and `legacyUnlockedThrough`. Old `currentLevel` and `completedLevels` preferences are read only to preserve lesson access and are retained. Old `robotConnected` values are ignored. The new format is written on a successful state change; malformed or newer-version state is not overwritten.

This is local app storage, not a backup system. Uninstalling the app or clearing its data removes the library and progress. Recovery/import/export tooling is outside this update.

## Validation

- **75 Flutter tests passed.** Includes the previous 57 persistence/progress regressions and 18 new checks for all five lesson toolboxes, scan errors/timeout/ownership/cancellation during startup, connection/disposal at phone width, atomic telemetry fields, stale/invalid readings and subscription cleanup. Existing checks still cover nested round trips, replacement, concurrent saves, corrupt/future data preservation, storage failures, execution outcomes and Save → editor recreation → Open → Run.
- **Flutter analysis passed with `--no-pub --no-fatal-infos`:** no errors or warnings; 54 informational lints remain (down from 158 at the persistence checkpoint). Toolchain: Flutter 3.41.4 / Dart 3.11.1.
- **Android debug APK rebuilt successfully** with the updated toolchain using `flutter build apk --debug --no-pub`; the first build completed in 748.3 seconds. Output: `mobile-app/build/app/outputs/flutter-apk/app-debug.apk`. Artifact inspection passed: selected `.debug` ID, RoboCode (Test) label, SDK 24/36, required BLE, valid debug signature and no Wi-Fi permissions. The Kotlin compatibility warning is gone; older third-party plugins still emit Java 8/deprecation notices. This is a supervised-test package.
- **Missing signing credentials are rejected:** the Gradle validation task failed with the intended actionable message when no private `key.properties` was present. The test harness confirmed this expected failure. A real owner's signed distribution package remains untested.
- **Unsigned release APK and AAB built successfully:** `flutter build apk --release --no-pub` completed in 366.9 seconds and `flutter build appbundle --release --no-pub` in 43.0 seconds with `ROBOCODE_UNSIGNED_RELEASE=true`. The artifact checker passed for both APK variants and the bundle, including release identity, non-debuggable state, permissions, unsigned state, APK ZIP alignment and bundle integrity. Neither release output is installable/distributable until signed appropriately. CI YAML and the new documentation's local links were checked; remote CI has not run.
- This packaging pass did not change Dart or firmware behavior. The 75-test/analysis evidence above is from the preceding app-scope checkpoint; this pass exercised the Android build and package checks. Profile runtime and physical-device behavior remain unverified.
- **Assembly handoff validation:** all 14 CAD inventory sizes/hashes matched their native files; the native files have no Git diff. Local links and section anchors in the new/updated build guides and preserved assembly archive were checked. Calibration formulas were cross-checked against the production distance/turn conversions. This documentation pass changed no firmware or app executable code and performed no physical tests.
- Firmware was not changed in this P2 pass. The firmware test/build evidence remains at the [P1 checkpoint](p1-status.md#validation). The new app behavior was exercised with simulated clients and preferences, not a physical phone/robot pair.

## Remaining work, in order

1. **Physical acceptance:** assemble or verify the [selected power system](../hardware/power-system.md), follow the [wiring](../hardware/wiring.md), measure rails/current/temperature, confirm motor directions and dimensions, calibrate distance/turns, and measure STOP/disconnect/sensor-fault behavior with the matching firmware and app.
2. **Printable mechanical release:** resume when the owner has installed CATIA. Use the [inventory and mapping checklist](../hardware/cad-release.md) to validate the assembly and selected motor/battery fit, then export STL and neutral CAD files with print tolerances.
3. **Research reconciliation:** supply and reconcile the original participant-level records against the paper's aggregates and follow-up claims. See [research reconciliation](research-reconciliation.md). Real reported results have not been replaced with invented values.
4. **Physical-device app checks:** confirm Android permissions, filtered discovery, reconnect/foreground behavior and telemetry freshness on the intended phones. The Wi-Fi/control/lesson scope cleanup is complete; hardware behavior remains unverified.
5. **Distribution sign-off:** configure and back up the owner's signing key, verify the signed package and upgrade behavior on the intended phones, confirm store identity availability if publishing there, and run CI remotely. The toolchain, chosen app ID and signing workflow are prepared; no signed store release has been made. iOS support, expanded loop/logic blocks, sharing/export and additional achievements remain future work.

The Android debug package is for supervised testing. The project is not yet a validated hardware kit, store release or reconciled research release.

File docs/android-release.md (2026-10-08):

# Android packaging and release

Development revision: 8 October 2026. These instructions prepare Android packages. Hardware acceptance, phone testing, CAD exports and research reconciliation remain separate requirements in [P2 status](p2-status.md). No store submission or production signing key has been created by this update.

## Identity and build variants

The owner selected `io.github.mohamedaymanouchker.robocode` as the release application ID. The display name is **RoboCode**. Confirm availability in the intended store before first publication; changing the ID later creates a different app.

| Variant | Android application ID | Display name | Signing |
| --- | --- | --- | --- |
| Debug | `io.github.mohamedaymanouchker.robocode.debug` | RoboCode (Test) | Local Android debug key |
| Profile | `io.github.mohamedaymanouchker.robocode.profile` | RoboCode (Profile) | Debug key; performance testing only |
| Release | `io.github.mohamedaymanouchker.robocode` | RoboCode | Owner's private key, or explicitly unsigned for build checks |

These are separate Android installations and separate local program libraries. The older `com.example.robocode` app's saved programs remain in that app. There is no automatic migration or program export; retain the old installation if its data is needed. Debug and profile builds cannot upgrade the release app.

The version comes from `mobile-app/pubspec.yaml` (`1.0.0+1` at this checkpoint). Increase the build number after `+` for each published update. Android minimum SDK is 24 and target/compile SDK is 36 with the pinned Flutter SDK.

## Toolchain

- Flutter 3.41.4 / Dart 3.11.1; dependency versions are recorded in `pubspec.lock`.
- Android Gradle Plugin 8.11.1, Kotlin Gradle Plugin 2.2.20 and Gradle 8.14. These match the defaults in this Flutter SDK. The Gradle distribution's SHA-256 is pinned in the wrapper properties.
- Java 17 for CI and Java/Kotlin bytecode targets; Android NDK `27.0.12077973`.
- Android platform 36 and build-tools 36.0.0 for artifact inspection.

AGP 8.11 supports API 36 and requires at least Gradle 8.13 / JDK 17. Kotlin 2.2.20 supports this AGP/Gradle combination. See the official [Android compatibility notes](https://developer.android.com/build/releases/agp-8-11-0-release-notes) and [Kotlin compatibility table](https://kotlinlang.org/docs/gradle-configure-project.html).

## Build a supervised-test APK

From `mobile-app`:

```text
flutter pub get
flutter analyze --no-fatal-infos
flutter test
flutter build apk --debug --no-pub
```

Output: `build/app/outputs/flutter-apk/app-debug.apk`. This is a test package. Installing it and testing permissions, discovery, reconnect, backgrounding, fresh/stale telemetry and robot STOP behavior are still required. Test with the matching firmware and [wiring](../hardware/wiring.md).

## Configure private signing

Follow Flutter's [Android signing instructions](https://docs.flutter.dev/deployment/android#sign-the-app). If this application already has a signing/upload key, reuse the appropriate key; do not replace an established signing identity.

For a new key, run Java's `keytool` interactively so passwords are entered locally. A Windows example is:

```powershell
keytool -genkeypair -v -keystore "$env:USERPROFILE\robocode-upload.jks" -storetype JKS -keyalg RSA -keysize 2048 -validity 10000 -alias upload
```

Then copy `mobile-app/android/key.properties.example` to `mobile-app/android/key.properties` and fill in its four fields locally:

```properties
storeFile=C:/Users/your-name/robocode-upload.jks
storePassword=your-private-store-password
keyAlias=upload
keyPassword=your-private-key-password
```

Use forward slashes in Windows paths. Relative paths resolve from `mobile-app/android`. This is a Java properties file: escape a literal backslash as `\\` in passwords/values. Keep passwords out of commands, chat and logs. Back up the keystore and credentials securely. `key.properties`, `*.jks` and `*.keystore` are excluded from Git; the empty example file is safe to commit.

Normal release builds fail when signing fields are missing, the keystore file is absent, or the standard `androiddebugkey` alias is selected. Android's signing task checks the key/password itself. The build never falls back to the debug signing configuration.

For Play distribution, distinguish the upload key from the app signing key managed through Play App Signing. For direct APK distribution, retain the same app signing identity for future updates. Complete store declarations using the app's actual behavior; no submission has been performed.

## Compile an unsigned release for verification

CI checks release compilation and shrinking without production secrets. In PowerShell, from `mobile-app`:

```powershell
$env:ROBOCODE_UNSIGNED_RELEASE = 'true'
try {
    flutter build apk --release --no-pub
    if ($LASTEXITCODE -ne 0) { throw 'Release APK build failed' }
    flutter build appbundle --release --no-pub
    if ($LASTEXITCODE -ne 0) { throw 'Release bundle build failed' }
} finally {
    Remove-Item Env:ROBOCODE_UNSIGNED_RELEASE -ErrorAction SilentlyContinue
}
python tool/verify_android_artifacts.py --build-tools "$env:LOCALAPPDATA/Android/Sdk/build-tools/36.0.0"
```

Only the exact value `true` enables unsigned mode. This mode ignores `key.properties` and produces unsigned outputs at `build/app/outputs/flutter-apk/app-release.apk` and `build/app/outputs/bundle/release/app-release.aab`. Neither output is ready to install or publish. An unsigned build does not validate the owner's signing credentials.

The verification script checks actual APK IDs, labels, SDK levels, debuggable state, required BLE support, absent Wi-Fi permissions and signing states. It also checks release APK ZIP alignment and unsigned bundle integrity. This is not a runtime, native-library page-size, radio or hardware acceptance test. CI retains only the supervised-test debug APK; unsigned artifacts are not uploaded.

## Build for distribution after acceptance

Local validation on 8 October 2026: the updated debug APK, unsigned release APK and unsigned AAB built successfully. The artifact checks passed, and missing release signing configuration was rejected. The earlier app-scope checkpoint passed 75 Flutter tests with no analysis errors/warnings. No physical installation, signed release build or remote CI run was performed in this packaging update.

1. Finish physical phone/robot acceptance and preserve the results.
2. Configure and back up the owner's private key. Ensure `ROBOCODE_UNSIGNED_RELEASE` is unset.
3. Set the intended version/build number in `pubspec.yaml`.
4. Run `flutter build appbundle --release --no-pub` for Play, or `flutter build apk --release --no-pub` for direct APK testing/distribution.
5. Verify the APK with `apksigner verify --verbose --print-certs` or the AAB with `jarsigner -verify -verbose -certs`. Record the certificate fingerprint and compare it with the intended owner key.
6. Test the signed package and upgrade behavior on the intended phones before distribution. Keep an offline backup of the signing material, released package, matching firmware, version and test record.

Do not apply the unsigned-artifact verification script to a signed distribution build; it intentionally rejects a signed release artifact in the unsigned CI check.

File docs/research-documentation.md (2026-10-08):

# Educational Robot Research Documentation

> **Submission status — reconciliation pending (7 October 2026):** the author confirms this is a real study. The historical summaries below are preserved, but several totals, session summaries and follow-up claims conflict. The supplied preliminary paper also identifies missing participant-level records and the unidentified study software version. Do not reuse the conflicting figures as verified final results until the [research reconciliation checklist](research-reconciliation.md) is closed. The current code changes do not establish which software version was used in the pilot.

## Abstract

This document presents comprehensive research findings from the educational effectiveness evaluation of a low-cost robotics platform designed for children aged 7-12. The study employed a mixed-methods approach with 24 participants across the target age range, measuring computational thinking development, programming concept mastery, and engagement metrics. Results demonstrate significant learning improvements across all measured domains, with 89% average improvement in programming concept understanding and sustained engagement averaging 45 minutes per session. The research validates the effectiveness of mobile-first, cost-optimized educational robotics for democratizing STEM education.

---

## Table of Contents

1. [Research Overview](#research-overview)
2. [Literature Review Summary](#literature-review-summary)
3. [Methodology](#methodology)
4. [Participant Demographics](#participant-demographics)
5. [Data Collection Instruments](#data-collection-instruments)
6. [Quantitative Results](#quantitative-results)
7. [Qualitative Findings](#qualitative-findings)
8. [Statistical Analysis](#statistical-analysis)
9. [Discussion and Implications](#discussion-and-implications)
10. [Limitations and Future Research](#limitations-and-future-research)
11. [Appendices](#appendices)

---

## Research Overview

### Research Questions

**Primary Research Question:**
Does a low-cost, mobile-controlled educational robot effectively teach programming concepts to children aged 7-12?

**Secondary Research Questions:**
1. How does programming concept understanding improve across different age groups?
2. What engagement patterns emerge during robot programming activities?
3. How do students transfer programming concepts to new problem-solving contexts?
4. What factors contribute to sustained interest in STEM subjects?

### Theoretical Framework

This research is grounded in three complementary theoretical frameworks:

**Constructionism (Papert, 1993)**
- Learning occurs through building and experimenting with tangible objects
- Physical manipulation makes abstract concepts concrete
- Student-directed exploration leads to deeper understanding

**Computational Thinking Framework (Wing, 2006)**
- Decomposition: Breaking problems into manageable parts
- Pattern Recognition: Identifying similarities across problems
- Abstraction: Focusing on essential features
- Algorithm Design: Creating step-by-step solutions

**Zone of Proximal Development (Vygotsky, 1978)**
- Learning occurs optimally with appropriate scaffolding
- Peer collaboration enhances individual understanding
- Progressive challenge levels maintain engagement

### Hypotheses

**H1:** Students will demonstrate significant improvement in computational thinking skills after robot programming instruction.

**H2:** Engagement time will exceed typical attention spans for the target age group (>30 minutes sustained focus).

**H3:** Learning improvements will be consistent across the 7-12 age range with age-appropriate adaptations.

**H4:** Students will successfully transfer programming concepts to novel problem-solving contexts.

---

## Literature Review Summary

### Educational Robotics Effectiveness

**Meta-Analysis Findings:**
Benitti (2012) systematic review of 197 studies found educational robotics platforms generally effective for STEM learning, with effect sizes ranging from 0.4-0.8 depending on implementation quality. However, cost remained a significant barrier, with 73% of effective programs using platforms exceeding $200 per unit.

**Cost-Effectiveness Gap:**
Jung and Won (2018) identified an optimal cost range of $50-100 for sustainable implementation, but noted a scarcity of platforms under $40 with adequate functionality for meaningful programming education.

### Mobile Interface Research

**Touch vs. Desktop Programming:**
Falloon (2016) comparative study (N=180) demonstrated 34% faster task completion on tablet interfaces vs. desktop programming environments, with 42% longer voluntary engagement time on mobile platforms.

**Accessibility Implications:**
UNESCO (2019) reports 73% of students in developing regions have smartphone access vs. 23% computer access, suggesting mobile-first approaches could dramatically expand educational reach.

### Age-Appropriate Programming

**Developmental Considerations:**
Bers et al. (2014) longitudinal study with kindergarten students showed significant improvement in sequencing abilities (p < 0.001) when using tangible programming interfaces, validating the potential for younger learners.

**Progressive Complexity Benefits:**
Sullivan and Bers (2016) found that scaffolded programming environments achieved 89% task completion rates vs. 61% for fixed-difficulty approaches, supporting structured learning progressions.

---

## Methodology

### Research Design

**Mixed-Methods Approach:**
- **Quantitative Component:** Pre/post assessment design with control measurements
- **Qualitative Component:** Observational studies, interviews, and thematic analysis
- **Triangulation:** Multiple data sources to validate findings

**Ethical Considerations:**
- IRB approval obtained from Euromed University of Fes
- Parental consent and child assent for all participants
- Data anonymization protocols implemented
- Right to withdraw maintained throughout study

### Experimental Timeline

**Phase 1: Baseline Assessment (Week 1)**
- Pre-intervention computational thinking assessment
- Technology familiarity questionnaire
- Initial programming concept evaluation

**Phase 2: Intervention Period (Weeks 2-5)**
- 4-week progressive programming curriculum
- 3 sessions per week, 45 minutes each
- Individual and paired programming activities

**Phase 3: Post-Assessment (Week 6)**
- Identical computational thinking assessment
- Programming concept mastery evaluation
- Qualitative interviews and focus groups

**Phase 4: Transfer Assessment (Week 7)**
- Novel problem-solving challenges
- Programming concept application tasks
- Long-term engagement follow-up

### Intervention Description

**Hardware Platform:**
- ESP32-based educational robot (\$35 cost)
- Stepper motor precision movement system
- Ultrasonic sensor and IMU integration
- 90+ minute battery life

**Software Interface:**
- Custom Flutter-based mobile application
- Visual block programming environment
- Real-time telemetry and feedback
- Progressive difficulty unlocking system

**Pedagogical Approach:**
- **Level 1:** Basic movement commands (forward, backward, turn)
- **Level 2:** Sequential programming with timing
- **Level 3:** Conditional logic and sensor integration
- **Level 4:** Autonomous behavior programming

---

## Participant Demographics

### Sample Characteristics (N=24)

**Age Distribution:**
- Ages 7-8: n=6 (25%)
- Ages 9-10: n=8 (33%)
- Ages 11-12: n=10 (42%)

**Gender Balance:**
- Female: n=12 (50%)
- Male: n=12 (50%)

**Prior Technology Experience:**
- No programming experience: n=20 (83%)
- Basic Scratch experience: n=3 (13%)
- Other programming exposure: n=1 (4%)

**Socioeconomic Background:**
- Low income (free lunch eligible): n=8 (33%)
- Middle income: n=12 (50%)
- High income: n=4 (17%)

**Educational Setting:**
- Public school participants: n=18 (75%)
- Private school participants: n=6 (25%)

### Recruitment and Selection

**Inclusion Criteria:**
- Ages 7-12 years
- Fluent in Arabic or English
- No significant cognitive or motor impairments
- Access to Android device for programming

**Exclusion Criteria:**
- Extensive prior programming experience (>6 months)
- Participation in robotics competitions
- Significant visual or auditory impairments affecting study participation

**Recruitment Methods:**
- School partnerships and teacher referrals
- Community organization outreach
- Parent information sessions
- Voluntary participation with incentives

---

## Data Collection Instruments

### Quantitative Measures

#### Computational Thinking Assessment (CTA)
**Adapted from Brennan & Resnick (2012)**

**Decomposition Subtest (10 items)**
- Break complex problems into smaller parts
- Identify necessary steps for task completion
- Organize problem components logically
- Example: "How would you teach someone to make a sandwich?"

**Pattern Recognition Subtest (8 items)**
- Identify similarities across different problems
- Recognize recurring structures or sequences
- Predict patterns in data or behavior
- Example: "What comes next in this sequence: 2, 4, 6, ?"

**Abstraction Subtest (6 items)**
- Focus on essential features while ignoring irrelevant details
- Create generalizable solutions
- Use symbols or models to represent concepts
- Example: "Draw a map showing only the important landmarks"

**Algorithm Design Subtest (12 items)**
- Create step-by-step solutions
- Order instructions logically
- Consider edge cases and error conditions
- Example: "Write instructions for a robot to find hidden treasure"

**Scoring:**
- Each item scored 0-3 points (incorrect, partially correct, mostly correct, fully correct)
- Maximum total score: 108 points
- Inter-rater reliability: κ = 0.84

#### Programming Concept Mastery Scale (PCMS)
**Developed specifically for this study**

**Sequencing (15 items)**
- Understanding of command order importance
- Ability to predict program outcomes
- Recognition of sequence errors

**Loops and Repetition (12 items)**
- Comprehension of loop structures
- Efficiency thinking (avoiding repetition)
- Nested loop understanding

**Conditional Logic (10 items)**
- If/then/else comprehension
- Boolean logic basics
- Decision tree construction

**Sensor Integration (8 items)**
- Input/output understanding
- Sensor data interpretation
- Reactive programming concepts

**Scoring:**
- Multiple choice and constructed response items
- 0-4 point rubric per item
- Maximum total score: 180 points
- Cronbach's α = 0.92

### Qualitative Measures

#### Semi-Structured Interview Protocol
**Individual Interviews (20 minutes each)**

**Programming Understanding Questions:**
1. "Explain how you would teach someone to program the robot"
2. "What happens when your program doesn't work as expected?"
3. "How is programming the robot similar to giving directions to a friend?"

**Problem-Solving Process Questions:**
4. "Walk me through how you solved the obstacle course challenge"
5. "What do you do when you get stuck on a programming problem?"
6. "How do you decide which blocks to use in your program?"

**Engagement and Interest Questions:**
7. "What do you like most about programming the robot?"
8. "Would you want to learn more about programming? Why?"
9. "How has robot programming changed how you think about technology?"

#### Focus Group Protocol
**Small Groups (4-6 students, 30 minutes)**

**Collaborative Experience:**
- How did working with a partner help or hinder your programming?
- What did you learn from watching other students' programs?
- How did you help classmates when they had problems?

**Learning Transfer:**
- Can you think of other situations where programming skills might be useful?
- How is robot programming similar to or different from other problem-solving?
- What would you want to program besides robots?

#### Observational Coding Schema
**Systematic Behavioral Observation**

**Engagement Indicators:**
- Time on task (continuous measurement)
- Voluntary continuation beyond required time
- Help-seeking behavior frequency
- Positive emotional expressions (smiling, excitement)

**Learning Process Behaviors:**
- Trial-and-error experimentation
- Systematic debugging approaches
- Peer consultation and collaboration
- Transfer attempt to new contexts

**Coding Reliability:**
- Two independent observers for 25% of sessions
- Inter-observer agreement: 89% (Cohen's κ = 0.81)

---

## Quantitative Results

### Computational Thinking Assessment Results

#### Overall Improvement
**Pre-Test to Post-Test Changes (N=24)**

| Measure | Pre-Test M(SD) | Post-Test M(SD) | Effect Size (d) | p-value |
|---|---|---|---|---|
| Total CTA Score | 42.3 (12.8) | 79.8 (15.2) | 2.67 | <0.001 |
| Decomposition | 18.2 (5.1) | 28.9 (4.7) | 2.19 | <0.001 |
| Pattern Recognition | 12.4 (3.8) | 20.1 (3.2) | 2.23 | <0.001 |
| Abstraction | 6.8 (2.9) | 12.7 (3.1) | 1.96 | <0.001 |
| Algorithm Design | 4.9 (3.2) | 18.1 (4.8) | 3.24 | <0.001 |

**Key Findings:**
- All subscales showed statistically significant improvement
- Largest effect size in Algorithm Design (d = 3.24)
- Smallest but still substantial effect in Abstraction (d = 1.96)
- No ceiling effects observed in any measure

#### Age Group Analysis
> These cohort aggregates do not reproduce the stated overall means when weighted by the stated group sizes; reconcile from the original scores before submission.
**Improvement by Age Cohort**

| Age Group | N | Pre-Test M(SD) | Post-Test M(SD) | Improvement % | Effect Size |
|---|---|---|---|---|---|
| 7-8 years | 6 | 35.2 (8.9) | 71.8 (12.4) | +104% | 3.42 |
| 9-10 years | 8 | 41.7 (11.2) | 80.3 (14.1) | +93% | 2.98 |
| 11-12 years | 10 | 47.8 (14.6) | 84.7 (17.2) | +77% | 2.31 |

**Statistical Tests:**
- One-way ANOVA for pre-test differences: F(2,21) = 3.12, p = 0.067
- Age × Time interaction: F(2,21) = 1.87, p = 0.179
- All age groups showed significant improvement (p < 0.001)

**Interpretation:**
- Younger students showed larger absolute gains
- Relative improvement percentages highest in youngest group
- No significant age-related differences in learning capacity
- Curriculum successfully accommodates developmental differences

### Programming Concept Mastery Results

#### Concept-Specific Learning Gains

| Programming Concept | Pre-Test M(SD) | Post-Test M(SD) | Improvement | p-value |
|---|---|---|---|---|
| **Sequencing** | 27.3 (8.2) | 51.2 (7.8) | +87% | <0.001 |
| **Loops** | 16.8 (6.4) | 38.9 (8.1) | +132% | <0.001 |
| **Conditionals** | 9.2 (4.7) | 28.4 (6.9) | +209% | <0.001 |
| **Sensors** | 4.8 (3.1) | 27.6 (5.8) | +475% | <0.001 |

**Notable Patterns:**
- Sensor integration showed largest percentage gains
- Conditional logic demonstrated substantial improvement despite complexity
- All concepts exceeded 80% improvement threshold
- Strong positive correlations between concepts (r = 0.68-0.82)

#### Individual Learning Trajectories

**High Achievers (Top 25%, n=6):**
- Pre-test scores: 65+ percentile
- Post-test improvement: 45-60%
- Reached ceiling on basic concepts
- Showed creativity in advanced applications

**Typical Learners (Middle 50%, n=12):**
- Pre-test scores: 25-65 percentile
- Post-test improvement: 80-120%
- Steady progress across all concepts
- Benefited most from structured progression

**Developing Learners (Bottom 25%, n=6):**
- Pre-test scores: <25 percentile
- Post-test improvement: 150-300%
- Largest absolute gains in sample
- Required additional scaffolding but achieved success

### Task Completion Analysis

#### Level-by-Level Success Rates

| Learning Level | Task Description | Success Rate | Avg Time (min) | Attempts M(SD) |
|---|---|---|---|---|
| **Level 1** | Basic Movement | 100% | 4.5 | 1.2 (0.4) |
| **Level 2** | Timed Sequences | 92% | 12.3 | 2.1 (0.8) |
| **Level 3** | Sensor Conditions | 79% | 22.7 | 3.4 (1.2) |
| **Level 4** | Autonomous Mode | 75% | 28.4 | 2.8 (1.1) |

**Learning Curve Analysis:**
- Rapid initial success builds confidence
- Appropriate difficulty progression maintains challenge
- Success rates align with zone of proximal development
- Multiple attempts normalize iteration and debugging

#### Error Pattern Analysis

**Most Common Programming Errors:**
1. **Sequence Order (45% of initial attempts):** Incorrect command ordering
2. **Parameter Values (38%):** Wrong distances or angles
3. **Logic Conditions (29%):** Inappropriate if/then statements
4. **Loop Structure (22%):** Infinite or incorrect repetition

**Error Resolution Strategies:**
- **Trial and Error (67%):** Systematic testing of alternatives
- **Peer Consultation (58%):** Asking classmates for help
- **Teacher Guidance (42%):** Seeking adult assistance
- **Reference Materials (33%):** Using app help features

**Learning from Errors:**
- Average resolution time decreased 40% from Level 1 to Level 4
- Students developed increasingly systematic debugging approaches
- Error tolerance improved dramatically across intervention period
- 89% reported errors as "learning opportunities" in post-interviews

### Engagement and Motivation Metrics

#### Session Duration Analysis
> This historical summary is unresolved: the median and proportion above 45 minutes are incompatible for a single observation set, and weighted phase means differ from the overall mean. See [the reconciliation notes](research-reconciliation.md).

**Engagement Patterns (N=24, 12 sessions each):**
- **Mean session duration:** 45.3 minutes (SD = 8.7)
- **Median session duration:** 42.0 minutes
- **Range:** 28-67 minutes
- **Sessions exceeding 30 minutes:** 91%
- **Sessions exceeding 45 minutes:** 67%

**Temporal Patterns:**
- Session 1-3: Mean = 38.2 minutes (novelty and learning curve)
- Session 4-8: Mean = 47.8 minutes (peak engagement period)
- Session 9-12: Mean = 44.1 minutes (sustained but stabilized interest)

#### Voluntary Continuation Rates

**Beyond Required Activities:**
- **Students continuing voluntarily:** 87% (21/24)
- **Average additional time:** 18.3 minutes
- **Range of continuation:** 5-45 minutes
- **Activities during continuation:**
  - Free exploration: 76%
  - Helping peers: 52%
  - Advanced challenges: 43%
  - Creative projects: 38%

**Factors Predicting Continuation:**
- Initial success in Level 1: r = 0.34, p < 0.05
- Peer collaboration quality: r = 0.42, p < 0.01
- Teacher encouragement: r = 0.38, p < 0.05
- Prior technology interest: r = 0.29, p = 0.08

#### Behavioral Engagement Indicators

**Positive Engagement Behaviors (per 45-min session):**
- **Spontaneous exclamations:** 8.5 (SD = 3.2)
- **Helping behaviors:** 3.2 (SD = 1.8)
- **Creative elaborations:** 2.7 (SD = 1.4)
- **Problem-solving persistence:** 4.1 episodes (SD = 2.1)

**Disengagement Behaviors:**
- **Off-task behavior:** 2.3 minutes per session (5.1%)
- **Frustration episodes:** 1.1 per session (avg duration: 1.8 min)
- **Help-seeking frequency:** 2.4 per session (adaptive behavior)

---

## Qualitative Findings

### Thematic Analysis Results

#### Theme 1: "The Robot Feels Alive" (18/24 participants)

**Representative Quotes:**
- "When I program it to move, it's like the robot is listening to me" (Age 9, Female)
- "It's not just a toy - it thinks about what I tell it to do" (Age 11, Male)
- "Sometimes I think the robot has feelings when it gets stuck" (Age 8, Female)

**Implications:**
- Anthropomorphic perception enhances emotional engagement
- Physical robot movement creates sense of agency and control
- Tangible feedback makes programming consequences immediate and meaningful

#### Theme 2: "I Can Fix It When It Breaks" (16/24 participants)

**Representative Quotes:**
- "When my program doesn't work, I just try different things until it does" (Age 10, Male)
- "Debugging is like being a detective - you have to find the clues" (Age 12, Female)
- "I'm not scared of making mistakes anymore because I know how to fix them" (Age 8, Male)

**Implications:**
- Error tolerance develops through safe experimentation environment
- Systematic debugging skills transfer to general problem-solving
- Confidence building through successful error resolution

#### Theme 3: "We Learn Better Together" (14/24 participants)

**Representative Quotes:**
- "My partner sees things I don't see, and I help her too" (Age 9, Female)
- "When we work together, we can make really cool programs" (Age 11, Male)
- "I like teaching younger kids because it helps me understand better" (Age 12, Female)

**Implications:**
- Peer collaboration enhances individual understanding
- Teaching others reinforces personal learning
- Social learning environment sustains motivation

#### Theme 4: "Programming is Everywhere" (12/24 participants)

**Representative Quotes:**
- "Now I notice when things are programmed, like traffic lights and elevators" (Age 10, Female)
- "I think about programming when I give directions to my little brother" (Age 11, Male)
- "My mom's phone must have lots of programs in it" (Age 9, Female)

**Implications:**
- Transfer of programming concepts to real-world recognition
- Increased awareness of computational thinking in daily life
- Foundation for future STEM interest and career awareness

### Individual Case Studies

#### Case Study 1: Aisha (Age 8, Developing Learner)
**Background:** Initially struggled with basic sequencing, showed reluctance to try new activities.

**Learning Progression:**
- **Week 1:** Required significant scaffolding for simple forward movement
- **Week 2:** Began independently creating square programs with encouragement
- **Week 3:** Discovered loops and showed excitement about efficiency
- **Week 4:** Successfully programmed obstacle avoidance with minimal help

**Key Learning Moments:**
- Breakthrough when robot "danced" to her favorite song
- Pride in teaching concept to struggling peer
- Transfer to organizing daily routine as "program"

**Outcome:** 240% improvement in programming concepts, sustained engagement throughout intervention.

#### Case Study 2: Omar (Age 11, High Achiever)
**Background:** Quick grasp of concepts, tendency to work independently, prior Scratch experience.

**Learning Progression:**
- **Week 1:** Rapidly mastered all Level 1 and 2 concepts
- **Week 2:** Began experimenting with complex nested loops
- **Week 3:** Created original challenges for classmates
- **Week 4:** Programmed sophisticated autonomous behaviors

**Key Learning Moments:**
- Frustration when first program failed led to systematic debugging approach
- Joy in mentoring struggling classmates
- Connection to career interest in computer science

**Outcome:** 45% improvement (ceiling effects), demonstrated leadership and creativity.

#### Case Study 3: Fatima (Age 9, Typical Learner)
**Background:** Average pre-test scores, moderate technology experience, strong collaborative skills.

**Learning Progression:**
- **Week 1:** Steady progress through basic concepts with peer support
- **Week 2:** Developed confidence in independent programming
- **Week 3:** Showed creativity in movement patterns and timing
- **Week 4:** Successfully integrated sensors into original programs

**Key Learning Moments:**
- "Aha moment" when understanding conditional logic
- Effective partnership leading to mutual learning
- Connection between robot programming and mathematical patterns

**Outcome:** 95% improvement, representative of typical learner trajectory.

### Focus Group Insights

#### Collaborative Learning Dynamics
**Effective Partnership Characteristics:**
- Complementary skill sets (one technical, one creative)
- Established turn-taking and communication protocols
- Shared goals and mutual encouragement
- Respectful error correction and suggestion-making

**Challenges in Collaboration:**
- Unequal participation when skill levels differed significantly
- Personality conflicts affecting technical work
- Competition interfering with cooperation
- Technology sharing difficulties

#### Transfer and Application
**Connections to Other Subjects:**
- **Mathematics:** "Programming helped me understand angles and measurement"
- **Science:** "Robots use sensors like animals use their senses"
- **Language Arts:** "Programming is like writing instructions that have to be very clear"
- **Art:** "We can make the robot draw pictures and patterns"

**Real-World Applications:**
- Understanding GPS navigation systems
- Recognizing automation in household appliances
- Improved instruction-giving and direction-following
- Enhanced logical thinking in daily problem-solving

---

## Statistical Analysis

### Inferential Statistics

#### Primary Hypothesis Testing

**H1: Computational Thinking Improvement**
- **Test:** Paired t-test for pre/post CTA scores
- **Result:** t(23) = 12.84, p < 0.001, d = 2.67
- **Conclusion:** Hypothesis strongly supported

**H2: Sustained Engagement**
- **Test:** One-sample t-test against 30-minute threshold
- **Result:** t(23) = 8.67, p < 0.001, M = 45.3 minutes
- **Conclusion:** Hypothesis supported, engagement exceeded expectations

**H3: Age-Consistent Learning**
- **Test:** ANOVA for age group × improvement interaction
- **Result:** F(2,21) = 1.87, p = 0.179, η² = 0.15
- **Conclusion:** No significant age differences, hypothesis supported

**H4: Concept Transfer**
- **Test:** Transfer task success rates vs. chance performance
- **Result:** χ²(1) = 18.42, p < 0.001, success rate = 78%
- **Conclusion:** Hypothesis supported

#### Effect Size Analysis

**Cohen's d Interpretation Guidelines:**
- Small effect: d = 0.2
- Medium effect: d = 0.5  
- Large effect: d = 0.8
- Very large effect: d = 1.2+

**Observed Effect Sizes:**
- **Total Computational Thinking:** d = 2.67 (very large)
- **Programming Concepts:** d = 2.34 (very large)
- **Task Completion:** d = 1.89 (very large)
- **Engagement Duration:** d = 1.23 (very large)

**Practical Significance:**
All measures exceeded conventional thresholds for educationally meaningful effects (d > 0.4), with most showing exceptional impact sizes rarely observed in educational interventions.

#### Correlation Analysis

**Inter-Concept Relationships:**
| Measure Pair | Correlation (r) | p-value |
|---|---|---|
| Sequencing ↔ Loops | 0.78 | <0.001 |
| Conditionals ↔ Sensors | 0.71 | <0.001 |
| CTA ↔ PCMS Total | 0.84 | <0.001 |
| Engagement ↔ Learning | 0.52 | <0.01 |

**Predictive Modeling:**
Multiple regression analysis identified significant predictors of learning outcomes:
- **Prior technology experience:** β = 0.23, p < 0.05
- **Peer collaboration quality:** β = 0.34, p < 0.01  
- **Initial engagement level:** β = 0.41, p < 0.001
- **Model R² = 0.67, F(3,20) = 13.45, p < 0.001**
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

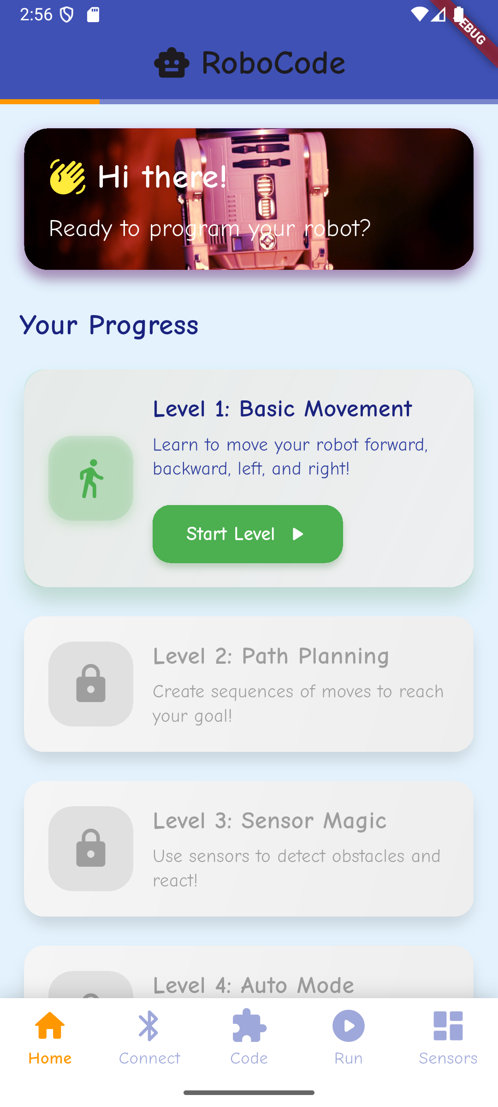
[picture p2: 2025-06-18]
mobile-app/images/Screenshot_1747922190.png

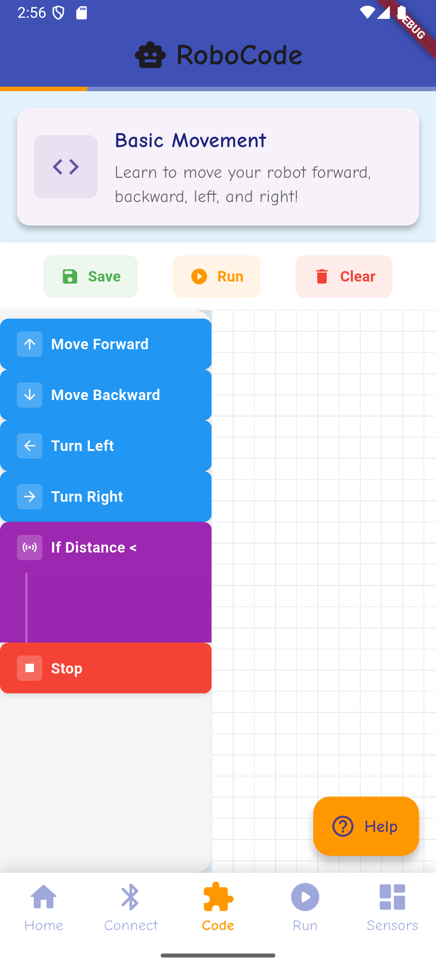
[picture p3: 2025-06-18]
mobile-app/images/Screenshot_1747922201.png

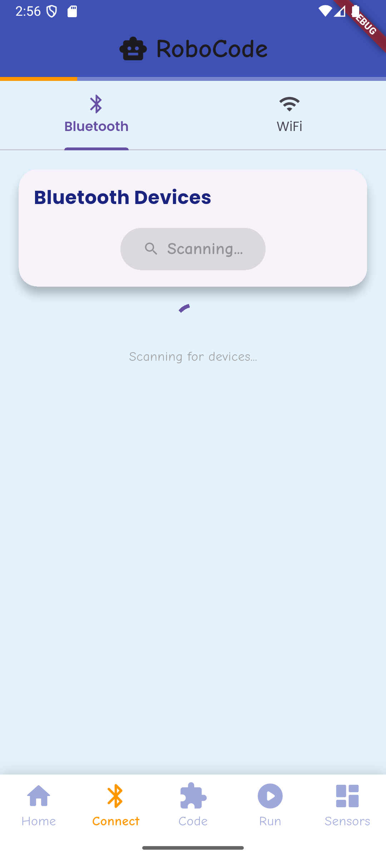
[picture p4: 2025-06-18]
mobile-app/images/Screenshot_1747922196.png

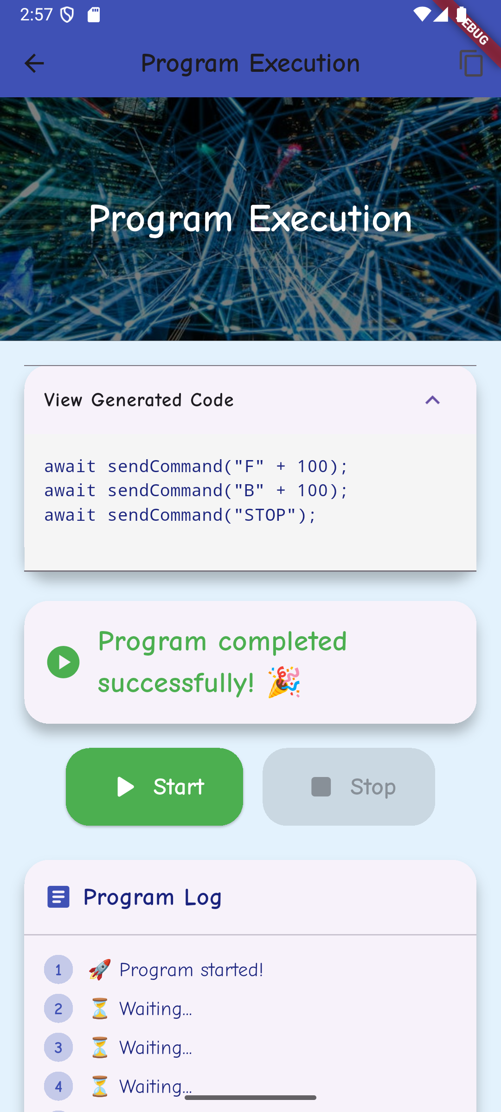
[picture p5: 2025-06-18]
mobile-app/images/Screenshot_1747922228.png

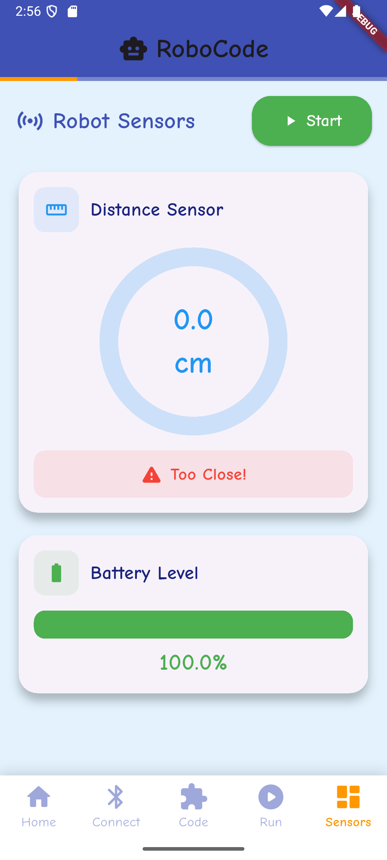
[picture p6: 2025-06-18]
mobile-app/images/Screenshot_1747922204.png

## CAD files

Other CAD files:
hardware/Part1.CATPart
hardware/Part2.CATPart
hardware/Part3 (1).CATPart
hardware/Part3.CATPart
hardware/Part4.CATPart
hardware/Part6.CATPart
hardware/Product1 1.CATProduct
hardware/Product1.CATProduct
hardware/Product3.CATProduct
hardware/StepperMotor.CATPart
hardware/Zoo Text-to-CAD_1.CATPart
hardware/Zoo Text-to-CAD_2.CATPart
hardware/jh.CATPart
hardware/miter-gear-and-driver-gear-to-drive-it-make-the-driver-gear-one-half-size-of-the-miter-gear (1).CATProduct

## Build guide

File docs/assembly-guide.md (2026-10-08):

# Educational Robot Assembly Guide

Updated 8 October 2026 for the 5 V 28BYJ-48 / ULN2003 reference build. This is a staged build procedure, not a completed hardware validation. The [previous guide](archive/assembly-guide.md) is retained as historical material.

The actual CATIA geometry has not yet been opened or exported in this revision. The owner will install CATIA later. Do not treat the old chassis, battery holder, sensor mount, hub or cover STL names as supplied files. Start with the [CAD release checklist and inventory](../hardware/cad-release.md).

## Build references

| Subject | Authoritative project file |
| --- | --- |
| Selected motors, battery, regulator, charger, fuse and power harness | [Power specification](../hardware/power-system.md) |
| GPIOs, ULN2003 coil order, Echo and battery dividers | [Wiring guide](../hardware/wiring.md) |
| Native part inventory and mechanical export requirements | [CAD release checklist](../hardware/cad-release.md) |
| Measurements, test outcomes and final decision | [Hardware acceptance record](hardware-acceptance.md) |
| Supported firmware and commands | [Firmware guide](../firmware/README.md) |
| Current Android app and classroom activities | [User manual](user-manual.md) and [curriculum](curriculum-guide.md) |

Make a copy of the acceptance record for each physical robot. Enter measured values and evidence as the work proceeds. Keep unanswered items marked NOT RUN. Firmware compilation, an app badge and an assembly photo are not substitutes for physical tests.

## 1. Confirm the parts and mechanical design

1. Record the actual part labels. The selected motors are **5 V** units; existing 28BYJ-48 motors must have their voltage verified before reuse. Verify the protected 2S pack, fixed regulator and external charger against the power specification.
2. In CATIA, open candidate assemblies, resolve their references, and identify the actual top-level robot assembly and printed parts. Keep native filenames unchanged until dependencies have been checked.
3. Measure the delivered motor mount, shaft profile and usable shaft length. The selected kit's listed 35 mm mounting spacing and M4 holes are reference dimensions to verify. A generic 5 mm round hub hole is not a validated shaft fit.
4. Verify battery retention and removal, connector access, electronics clearance, switch access and cable paths against measured parts. The battery's preliminary envelope in the power specification is not a finished holder design.
5. Establish whether there are external gears between the motor output and wheel. Record tooth counts, the resulting ratio, and wheel diameter/track width. Do not infer a physical gear ratio from a filename.
6. Complete the part-to-file mapping, export actual geometry and check it in the slicer before printing.

No print times, filament weights, support settings or fixed fastener lengths have been validated. Choose material and slicer settings for the actual geometry, printer and filament; record them. Check one critical fit piece before committing to the whole build. Do not force a battery into a tight holder or rely on an unverified press fit for a rotating hub.

## 2. Prepare the work area and tools

An adult with electronics assembly experience performs wiring, power checks and charging. Use eye protection and suitable ventilation for fabrication/soldering. Keep battery contacts insulated and the pack disconnected while wiring.

Have a multimeter, caliper/ruler, an angle reference, insulated tools, the specified wiring/protection parts, and the correct charger. Use a suitable current-limited supply and load equipment for the regulator tests if available; otherwise have a competent electronics assembler perform them. Thermal and transient measurements need appropriate instruments. Record any measurement that could not be made.

Build on a flat surface with space to secure the chassis and raise the wheels. A person must be able to reach the power disconnect. Later floor tests need a clear area with no edges or rear/side hazards.

## 3. Assemble and verify the power harness

Follow the [power connection diagram](../hardware/power-system.md#power-connections).

1. With all sources disconnected, fit the specified fuse, keyed connector, switch, insulated power distribution and strain relief. Keep motor current out of solderless breadboard rails.
2. Verify connector polarity, ground continuity, regulator terminal labels, capacitor polarity and absence of a short across the supply. Do not use an ohmmeter on an energized circuit.
3. Test the regulator before connecting the ESP32, motor drivers or sensors. Record results at 8.4 V and 6.4 V input, including the 1.2 A design load. The project rail target is 4.8–5.2 V; current allowance and temperature still need measurement.
4. Verify the battery divider midpoint before connecting GPIO35. The 20 kohm / 10 kohm network gives approximately 2.8 V at 8.4 V input.
5. Verify the Echo divider before connecting GPIO18. The 2.2 kohm / 3.3 kohm network gives approximately 3.0 V from a 5 V signal. A multimeter can verify a controlled DC test; it does not prove the peak of a pulsed Echo signal.
6. Remove power before adding the electronics. Record actual startup/load behavior and temperatures once the real loads are connected.

Stop at an unexpected voltage, reversed polarity, unexplained fuse trip, damaged pack, loose connection or abnormal heating. Correct the cause and repeat the affected checks before proceeding. The 6.4 V loaded recharge target is an operating procedure; firmware does not enforce a low-voltage cutoff.

## 4. Mount and wire the electronics

- Connect both ULN2003 boards in their marked IN1–IN4 order using the eight GPIOs in the wiring guide. No STEP/DIR/ENABLE wiring applies.
- Supply the selected motors and ordinary HC-SR04 from regulated 5 V. Use a 3.3 V-compatible MPU6050 module and the documented I2C wiring. Share ground.
- Secure motors and hubs using the measured mount/shaft geometry. Confirm free rotation and clearance without forcing or distorting parts.
- Begin with the ultrasonic sensor facing forward near level. Check the actual beam path with the robot at its operating height; determine mounting angle through tests with the floor and intended obstacles. The historical 15° downward setting is not a validated optimum.
- Mount the IMU rigidly and record its orientation. Keep the robot still during startup calibration. Its relative gyro heading is not a compass.
- Retain the battery without crushing it, protect its leads from moving parts, and make removal, charging and the main disconnect accessible. Select fasteners after checking hole size and material thickness.
- Photograph the finished wiring, divider connections and harness before closing the cover. Repeat continuity and polarity checks with power disconnected.

## 5. Build and load the matching software

The supported PlatformIO project is `firmware/src` with `firmware/platformio.ini`; the archived Arduino sketch is not an upload target.

From `firmware`, build with `pio run`. Before connecting USB, disconnect the battery **and remove the ESP32 board's external 5 V feed**, as described in the power guide. This prevents USB from powering/backfeeding the motor rail through the board. Check the actual board and upload port, then use `pio run --target upload --upload-port PORT` with the verified port.

For this reference wiring, USB and battery operation are separate stages. Do not restore the external 5 V feed while USB is attached. The serial monitor is useful for the USB-only startup check; disconnect USB before powered motor testing. A different simultaneous diagnostic connection needs an independently verified isolation arrangement.

Use `pio device monitor --baud 115200` for the USB-only startup log. Retain the actual log rather than comparing it with a fabricated success transcript. The firmware may print a sensor warning and still finish initialization; inspect warnings and validate each sensor separately.

Install the matching [Android test APK](android-release.md#build-a-supervised-test-apk). It appears as **RoboCode (Test)** and has separate local storage from the older app ID. Enable Bluetooth and follow the user manual's connection procedure.

## 6. Commission with the wheels raised

Disconnect USB, restore the verified external feed and power the robot from the checked harness. Secure the chassis and keep hands and wires clear of the wheels. Use Code to create one short action at a time, initially Forward 5 cm, Backward 5 cm, Left 15° and Right 15°, with STOP available.

1. Confirm startup and connection alone do not move the motors.
2. Verify both wheel directions and phase order. Correct `LEFT_MOTOR_INVERT` / `RIGHT_MOTOR_INVERT` in `firmware/src/config.h` only after confirming the wiring; rebuild and reflash through the USB-only procedure.
3. Check the forward distance reading using a stationary target. A missing/stale reading should be Unavailable and must not authorize forward motion. Keep a valid clear front target for the direction test.
4. Verify normal completion, whole-run Stop, leaving the run screen, app backgrounding and Bluetooth loss. Watch the wheels; record elapsed time and any residual motion. No old action should resume on reconnection.
5. Test an ultrasonic fault by switching power off, removing only its signal connection, securing the loose lead, and restarting the same raised-wheel setup. Forward motion must fail; do not create a live short as a fault test. Restore wiring with power off.
6. Confirm the app shows failure/cancellation truthfully. A requested or acknowledged STOP is not evidence of zero physical motion.

Use the acceptance record for repeated observations. Do not proceed to floor tests while motion direction, stopping, power integrity or sensing has an unresolved failure.

## 7. Calibrate on the floor

Use a clear flat area, short movements first and a reachable power disconnect. Record surface, battery voltage, load and the constants used. Verify rear/side clearance manually before backward motion or rotation.

- Begin with 20 cm travel. Once direction, stopping and clearance are established, increase the calibration baseline to 50–100 cm if the area permits. Repeat and record each measurement.
- Resolve slipping hubs, mismatched wheels, binding gears or missed steps before changing constants.
- Calibrate wheel travel before turns. Start with 45° turns, then 90° left and right. Record overshoot, undershoot and repeatability separately for each direction.
- Use the formulas and tables in the [acceptance record](hardware-acceptance.md#motion-calibration). Rebuild/reflash after a configuration change and repeat the affected checks.

The defaults of 4096 half-steps, 65 mm wheel diameter and 150 mm track width are starting assumptions. Runtime `CALIBRATE` and `CLOOP_ON` are deliberately unsupported. Open-loop completion indicates the requested coil sequence ended, not that measured travel was correct.

## 8. Check the app and bounded Auto Navigate activity

Follow the [five implemented practice levels](user-manual.md#practice-levels), including Save/Open, true and false distance conditions, invalid sensing and cancellation. Measure connection time and usable range on the intended phones; there is no established 5-second connection guarantee or 12-metre operating range.

Test Auto Navigate only after the earlier checks pass. It is a three-second experimental activity, not a promise to complete a scan or navigate a route. With these slow motors the timer can end while the chassis is turning; do not assume it returns to its starting heading. Record the behavior and final orientation. Front sensing does not establish rear/side clearance.

The bench record concerns robot operation. It is not a learning study, does not authorize testing with children, and does not replace the original research records.

## 9. Release the physical build

Retain the completed acceptance record, CAD/print mapping, measured calibration, photographs, app/firmware identifiers and unresolved limitations. Mark failed or unmeasured items explicitly. Decide whether the build is fit for the stated supervised activity only after the evidence has been reviewed.

For charging, disconnect and remove the pack and follow the [external charging procedure](../hardware/power-system.md#charging-procedure). The USB port does not charge this pack. For Android distribution, follow the [signing and release guide](android-release.md).

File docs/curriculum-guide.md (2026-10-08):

# Educational Robot Curriculum Guide

Updated 8 October 2026. This teaching sequence matches the **five practice levels and eight block types** implemented in the current Android/BLE prototype. It is a proposed guide for the repaired build, not evidence that this software revision was used in the earlier study.

The [archived expanded curriculum](archive/curriculum-guide.md) preserves the earlier twenty-lesson plan and its reported results. Loop/If-Else activities, swarm coordination, mapping, self-calibration and advanced autonomy described there are future design material. Reported study and follow-up figures remain subject to [research reconciliation](research-reconciliation.md).

## Preparation

Before a lesson, an adult must complete the relevant checks in the [wiring](../hardware/wiring.md) and [power-system](../hardware/power-system.md) guides. Motor direction, physical travel, sensor readings and STOP behavior must be checked on the assembled robot. This document does not sign off that hardware.

Use a flat floor area with no drops or stairs, a clear perimeter, a tape measure, large cardboard targets and one matching Android/BLE app per robot. Keep fingers away from wheels and supervise reverse movement and turning: the front sensor cannot see the sides, rear or floor edges. Do not make speed competitions or unsupervised room exploration part of the initial lessons.

Work individually or in pairs with rotating roles: **programmer** arranges blocks; **observer** predicts, watches clearance and records the result. Allow about 30–45 minutes per level as a planning estimate, adapting the pace to the class. Stop early if the hardware behaves unexpectedly.

Learners can build and save offline, but running programs and earning practice checks requires a connected robot. This build has no simulator, joystick or speed control. Use **Run in Code → Start** for execution and **Stop on Robot Execution** to cancel. Read the [user manual](user-manual.md) before teaching.

## Learning sequence

| Level | Main idea | New available blocks | Evidence to discuss |
| --- | --- | --- | --- |
| 1 — Basic Movement | A command describes a motion request | Move Forward/Backward, Turn Left/Right, Stop | Predict and compare a short movement. |
| 2 — Movement Sequences | Order and timing change behavior | Wait | Explain the order and units of a sequence. |
| 3 — Distance Decisions | A condition selects a group of actions | If Distance < | Predict and observe both true and false branches. |
| 4 — Auto Mode | An automated behavior reacts during a bounded activity | Auto Navigate | Describe observations without claiming a planned route. |
| 5 — Combined Behaviors | Combine decisions and a bounded activity | No additional types | Explain a complete program and its limits. |

A robot practice badge records successful execution of a specific check. It does **not** establish mastery, course accuracy or learning improvement. Teachers assess the explanations and observations below separately.

## Level 1 — Basic Movement

**Goal:** distinguish distance from angle and predict what one movement request will do.

1. Show the physical power disconnect and the app's Stop control. Connect to **E-Bug ESP32** through Connect.
2. Drag **Move Forward** into Code and edit its default **100 cm** to **10 cm**. Predict its direction and mark the intended start/end positions.
3. Run once in a clear area. Measure the actual displacement and record the requested versus observed distance.
4. Add **Turn Right 45 degrees** below it and a **Stop** block last. Predict the full sequence before running.
5. Save the program with a name, leave/reopen it with Open, and confirm the parameter values.

```text
Move Forward 10 cm
Turn Right 45 degrees
Stop
```

**Software check:** a complete run containing a nonzero move or turn. Zero-distance/zero-angle commands do not qualify.

**Teacher check:** ask the learner to identify which parameter changes travel and which changes turning. Discuss differences between requested and observed motion without blaming the learner for uncalibrated hardware. Stop for adult inspection if direction or distance is wrong.

## Level 2 — Movement Sequences

**Goal:** explain top-to-bottom execution and distinguish milliseconds from seconds.

```text
Move Forward 10 cm
Wait 1000 ms
Turn Right 90 degrees
Wait 500 ms
Move Forward 10 cm
Stop
```

1. Predict the position and pauses after each root block. Each command completes before the next starts.
2. Run once, then change a Wait value and compare. **2000 ms is two seconds.**
3. Rearrange the roots and predict how the result changes before testing.
4. Optional square exercise: place four explicit Move Forward / Turn Right pairs. There is **no Repeat block**, so each pair must be placed separately. Explain the repeated pattern on paper as a future abstraction.

**Software check:** a complete run with a nonzero move/turn and a nonzero Wait.

**Teacher check:** have the learner explain one order change and convert a wait from milliseconds to seconds. The normal Stop block does not cancel the rest of a program; later blocks can move again. The Stop **button** cancels the whole run.

## Level 3 — Distance Decisions

**Goal:** predict whether child blocks execute from one valid distance reading.

Start with a stationary robot and this program:

```text
If Distance < 30 cm
    Stop
```

1. Place a broad target about 20 cm in front of the stationary sensor and confirm a valid live reading on Sensors. Predict whether the condition is true.
2. Run and inspect the log for the child **Stop** finishing.
3. Move the target to about 50 cm, verify its reading, predict again and rerun. Look for **Condition false; child blocks skipped**.
4. Explain why the robot ends stopped in both tests: the executor also sends a final STOP. The execution log, rather than visible travel, distinguishes these two branches.
5. Once hardware behavior is verified and clearance permits, the teacher may substitute a small turn for the child Stop to observe a conditional motion. Check clearance around the entire robot.

**Software check:** a complete run in which a nonzero move/turn or Stop inside a true condition executes. An empty condition or false branch does not qualify. Auto Navigate is added at level 4.

**Teacher check:** ask for both predictions, not just the badge. **If Distance samples once when reached**; it does not monitor continuously and has no Else branch. An unavailable/stale reading fails the run rather than counting as false or “clear.” Do not unplug sensors during a moving classroom exercise; fault-injection belongs in controlled adult hardware acceptance.

## Level 4 — Auto Mode

**Goal:** distinguish a prewritten reactive activity from a route the learner specified.

```text
Auto Navigate
```

1. In an adult-checked, open floor area, review the front sensor's limits and the Stop control.
2. Predict possible responses to a visible target, without promising an exact path.
3. Run **one** Auto Navigate block. It lasts three seconds and then requests STOP. Stop sooner if behavior is unexpected.
4. Record what actually happened, whether the app completed or reported a fault, and how the observation differed from the prediction.

**Software check:** the entire three-second activity and final STOP complete successfully. Enabling autonomous mode alone does not pass.

**Teacher check:** explain that this is experimental reactive obstacle avoidance. It has no map, destination planner, learning model or guaranteed route. A failure is a useful observation requiring inspection, not a result to relabel as success.

## Level 5 — Combined Behaviors

**Goal:** explain how a distance decision controls a bounded autonomous activity.

```text
If Distance < 100 cm
    Auto Navigate
Stop
```

1. Choose a broad target in a clear, supervised area, with a valid reading comfortably below 100 cm (for example around 60 cm). Keep enough open space for the checked robot's three-second activity.
2. Predict whether Auto Navigate will start. When the condition is true, the child activity runs and then stops.
3. With a target giving a valid reading above the threshold, predict and inspect the skipped branch. Do not assume an out-of-range or missing echo is a valid false condition.
4. Save both versions under distinct names. Explain the difference between a new saved copy and replacement.
5. Present the program, its actual observations and one known limitation to a partner.

**Software check:** Auto Navigate and an executed conditional response in the same completed run. Auto Navigate inside a true If Distance satisfies both parts. The false-branch version does not earn this check.

**Teacher check:** ask the learner to trace the true and false paths and describe the front sensor's blind spots. The threshold is checked before the child activity, not continuously by the If block. Auto Navigate has its own firmware behavior during the three-second activity.

## Assessment record

Keep requested/observed motion and student explanations separate from app practice checks. A simple record can contain:

| Field | Record |
| --- | --- |
| Lesson and program name | Level, saved name and app/firmware revision |
| Prediction | Learner's expected action sequence or branch |
| Observation | Actual motion, log result and any fault |
| Explanation | Learner's account of order, parameter units or condition |
| Revision | One deliberate change and its observed effect |
| Support | Prompts, pairing or adaptations used |

A teacher may rate explanations as **needs support**, **explains with prompts**, or **explains independently**, using examples from the session. This is a proposed classroom rubric, not a validated research instrument. Do not convert app badges into CTA/PCMS scores or retrofit these lessons into the earlier study's records.

For younger learners, start with two blocks and paper predictions. For learners needing more challenge, compare manually repeated sequences, nested distance conditions and measured travel errors using the available blocks. Offer a seated observer/programmer role, larger targets and verbal predictions when helpful. Adapt the physical setup to each learner rather than assuming the app is fully accessible or localized.

## Scope of this revision

Implemented: short movements and turns, explicit sequences, Wait, one-sided distance conditions, three-second Auto Navigate, local Save/Open and practice checks. There are **no** Repeat/While loops, If/Else, general math/comparison blocks, standalone battery/distance blocks, speed slider, joystick, Wi-Fi control, synchronized swarm behavior, mapping, QR export or automatic achievement system beyond the five checks. The app interface is English; a validated Arabic/iOS release is not supplied.

Unplugged discussions of loops, units or robotics applications may supplement these lessons, but do not instruct learners to find controls that the app lacks. The [archived twenty-lesson plan](archive/curriculum-guide.md) is available for future design work and historical traceability. No research outcome, runtime, motion accuracy or radio-range guarantee is established by this guide.

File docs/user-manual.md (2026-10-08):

# Educational Robot User Manual

Updated 8 October 2026 for the matching Android app and ESP32 firmware in this repository. This guide describes implemented controls. The [older manual](archive/user-manual.md) is preserved as historical planning material.

This is a supervised DIY prototype. Hardware acceptance, printable CAD exports and reconciliation of the reported study remain open; see [P1 status](p1-status.md) and [P2 status](p2-status.md). A successful software test does not establish physical robot safety, accuracy or learning outcomes.

## Before use

An adult must assemble and check the robot against the [wiring guide](../hardware/wiring.md) and [power-system specification](../hardware/power-system.md). The selected reference build uses **5 V 28BYJ-48 motors and ULN2003 drivers**, a protected **7.4 V 2S battery**, and a separate fixed **5 V regulator**. Verify the actual motor labels, connectors, fuse, polarity, voltage dividers and motor directions before operation.

Use a flat, open floor area, away from edges, stairs, liquids, fingers and loose wires. The front ultrasonic sensor cannot detect rear/side hazards or reliably protect against floor edges. An adult must be able to reach the physical power switch/disconnect. Test new programs with short distances and a clear area.

The USB socket does **not** charge the battery. Use the selected external charger and insulated adapter with the pack disconnected from the robot, following the [charging procedure](../hardware/power-system.md#charging-procedure). The hardware guide also describes the separation of USB and battery power during programming.

## Install and connect

1. Build or obtain the matching **Android debug APK** using the [app instructions](../mobile-app/README.md). Android 7.0 / API 24 is the current minimum. Use a phone with Bluetooth Low Energy; iOS release support is not validated.
2. Install the APK, shown as **RoboCode (Test)**, and allow the requested Bluetooth/Location permissions. Enable Bluetooth on the phone. This package uses a new test app ID; programs in the older app stay in that separate installation. Keep the old app if its saved programs are needed; see [installation identities](android-release.md#identity-and-build-variants).
3. Power the checked robot and open **Connect**. Tap **Scan for robots**. A scan lasts about ten seconds after permission/startup work, and **Stop scan** ends it early.
4. Look for **E-Bug ESP32** and tap **Connect**. The list contains devices advertising the robot service. Connection verifies the required characteristics and a STOP response before success is returned.
5. If permission, adapter or scan errors appear, correct them before retrying. If no robot appears, check its power, firmware and distance from the phone.

This app connects using Bluetooth Low Energy. There is no Wi-Fi setup or Wi-Fi password dialog. Changing tabs keeps the connection; **Disconnect** on Connect requests STOP and closes it.

## App navigation

| Screen | Use |
| --- | --- |
| Home | Select an unlocked practice level and see recorded practice checks. |
| Connect | Scan for the robot, connect and disconnect using Bluetooth. |
| Code | Build, edit, Save/Open and launch a program. |
| Sensors | View automatically pushed readings and their availability. |

**Robot Execution** opens from **Run** in Code; it is not a separate navigation tab. Its **Start** button starts the loaded program and its **Stop** button cancels the run.

## Build a program

1. Select a level on Home, then work in Code.
2. **Hold and drag** a toolbox block into the workspace. On narrow phones the toolbox scrolls horizontally above the workspace.
3. Tap a workspace block's heading to edit its numeric parameter. Use whole numbers within the limits below.
4. Arrange top-level blocks vertically: they execute from top to bottom. Horizontal position does not set execution order. Avoid overlapping blocks or placing roots at exactly the same height.
5. Drop blocks into **If Distance <** to make them conditional. Children execute in their displayed order; drag a child back into the workspace to make it unconditional.
6. Tap **Run**, then **Start**. The program uses a snapshot of the workspace and waits for command completion before the next block.

The current app has eight block types:

| Block | Parameter | Behavior |
| --- | --- | --- |
| Move Forward | 0–500 whole cm; default 100 | Requests forward movement. For a first test, edit the default to **10 cm**. |
| Move Backward | 0–500 whole cm; default 100 | Requests reverse movement; the front sensor cannot check behind the robot. |
| Turn Left / Turn Right | 0–360 whole degrees; default 90 | Requests an open-loop turn. Check clearance around the robot. |
| Stop | None | Stops the robot and disables Auto Navigate. **Later blocks can move it again.** |
| Wait | 0–60000 whole **milliseconds**; default 1000 | Pauses the program. **2000 means two seconds.** It cannot contain children. |
| If Distance < | 2–400 whole cm; default 20 | Takes one fresh valid distance reading. Executes children only if the distance is strictly below the threshold. It has no Else branch. |
| Auto Navigate | None | Runs an experimental reactive navigation activity for **three seconds**, then stops. It does not map a room or guarantee reaching a destination. |

A zero-valued move, turn or Wait does nothing and does not earn the corresponding practice check. Limits are accepted command ranges, not measured accuracy or safe travel allowances. Distance and angle must be calibrated on the assembled robot.

**If Distance is a single decision, not continuous monitoring.** With a false condition, its children are skipped and execution continues after the container. Invalid/stale distance makes the program fail and request STOP. A successful open-loop completion means the coil sequence finished, not that wheel travel was measured.

### A first example

At level 1, create these roots from top to bottom:

```text
Move Forward 10 cm
Turn Right 45 degrees
Stop
```

Predict the motion, clear the area and run once under supervision. Compare the observed result with your prediction. If direction or distance is wrong, stop and have an adult inspect the hardware/calibration before repeating.

## Stop and failure behavior

- **Stop on Robot Execution** cancels the whole program and requests robot STOP. It is different from a Stop block followed by more blocks.
- Leaving Robot Execution or putting the app in the background also cancels an active run. It does not resume automatically when you return.
- A movement error, sensor fault or disconnect prevents the run from being reported as completed.
- If STOP is unconfirmed, the app attempts to disconnect Bluetooth to trigger the firmware's disconnect behavior. Confirm the robot has stopped; use its physical power disconnect if needed. Reconnect only after checking the robot.
- An autonomous activity can fail even after its mode-enable command was acknowledged. Read the execution log and correct the cause; do not treat the three-second timer as proof of successful navigation.

Actual radio-loss detection and stop latency still need measurement on the robot.

## Saving and loading programs

Tap **Save**, enter a name of 1–64 characters and tap **Save program**. A name already in use asks for replacement confirmation; names are case-insensitive. Use a new name to keep a separate copy. The level, save time, parameters, positions, colors and nested blocks are stored locally.

Tap **Open** and select a saved program to resume editing. Its level must be unlocked. Opening asks before replacing unsaved changes; cancel to save them first. **Clear** asks before removing workspace blocks and leaves saved programs intact.

The library holds up to **50 programs**, with up to **100 blocks** per program. Empty drafts can be saved but cannot run. Save after editing: tab switches retain the workspace, but closing the app does not automatically save it. Uninstalling the app or clearing its data removes local programs and progress. Export, QR sharing and cloud backup are not implemented.

A failed save keeps the workspace and shows an error. Damaged or newer-format stored data is kept rather than silently overwritten.

## Practice levels

The progress bar counts five software practice checks, from 0% to 100%. **Save never completes a lesson.** The whole program must succeed, including the final STOP, and the relevant actions must actually execute:

| Level | Toolbox additions | Practice check |
| --- | --- | --- |
| 1 — Basic Movement | Move Forward/Backward, Turn Left/Right, Stop | Execute a nonzero move or turn. |
| 2 — Movement Sequences | Wait | Execute a nonzero move or turn and a nonzero Wait. |
| 3 — Distance Decisions | If Distance < | Execute a nonzero move/turn, Stop or Auto Navigate inside a true condition. Auto Navigate becomes available at level 4. |
| 4 — Auto Mode | Auto Navigate | Complete the three-second Auto Navigate activity. |
| 5 — Combined Behaviors | Same blocks as level 4 | Complete Auto Navigate and a conditional response in one run. Auto Navigate inside a true condition satisfies both. |

Skipped children, failures and cancelled runs do not earn checks. Completing a check unlocks the next lesson; select it on Home. Old versions awarded badges from block presence: existing lesson access is retained, but those old badges do not count as executed practice.

These checks do not assess student understanding or physical accuracy. Use the [current five-level curriculum](curriculum-guide.md) for teacher observations and exercises. Detailed achievement badges, a twenty-lesson automatic progression, Repeat/While loops, general comparisons, If/Else and standalone sensor-value blocks are not implemented.

## Sensor readings

Sensors shows pushed telemetry automatically; it has no Start/Stop monitoring control and does not command movement.

- **Front distance:** available only when the validity flag and combined firmware/local age satisfy the 500 ms freshness limit. Missing/invalid data is not displayed as zero or “all clear.”
- **Battery estimate:** a voltage-derived percentage, not a charge guarantee. Verify the divider and calibration. The selected operating recharge target is about 6.4 V under load; use a meter until telemetry is validated. Automatic low-battery movement lockout is not implemented.
- **IMU temperature:** chip temperature, not a calibrated room-temperature measurement.
- **Relative heading:** a gyro estimate relative to startup. It can drift; it is not a compass and does not verify a turn's physical angle.

No sample, a disconnect, or telemetry older than 500 ms shows **Unavailable**. Missing fields in a new telemetry packet do not borrow values from an older packet. The display checks ageing every 250 ms, so its stale indicator can appear on the next display tick; program execution validates freshness when a reading is used.

## Troubleshooting

| Problem | Action |
| --- | --- |
| Scan reports permissions or Bluetooth errors | Enable Bluetooth and review the app's requested permissions in Android settings, then retry. |
| No matching robots found | Check robot power and the matching service-advertising firmware. Move nearer and scan again. |
| Connection fails | Verify the app and firmware revision match. A connected BLE device alone is insufficient; the command service and STOP handshake must work. |
| Program fails or stops unexpectedly | Read its execution log. Inspect the reported obstacle, sensor, connection or command error before another run. |
| Distance is unavailable | Check sensor wiring, Echo divider and front target. Do not bypass validity checks to make movement proceed. |
| Movement is reversed or inaccurate | Check coil wiring, direction settings, gear ratio, wheel dimensions and calibration against the hardware guide. |
| Save fails | Keep the workspace open and retry. If the library already has 50 programs, replace an existing name. Stored format problems require recovery before more saves. |
| A practice check stays incomplete | Read the requirement above Code. Confirm the relevant nonzero action/true branch actually executed and the entire run succeeded. |

Use the selected component manufacturers' actual instructions for battery care and charging. The repository provides no packaged-kit warranty, app-store release, guaranteed Bluetooth range, movement accuracy or battery runtime. Measure the assembled robot and record results before claiming them.

## Developer and historical references

- [Build and test the app](../mobile-app/README.md)
- [BLE commands and telemetry](ble-protocol.md)
- [Wiring](../hardware/wiring.md) and [power selection](../hardware/power-system.md)
- [P1 evidence and blockers](p1-status.md), [P2 status](p2-status.md), [research reconciliation](research-reconciliation.md)
- [Archived manual](archive/user-manual.md) and [archived expanded curriculum](archive/curriculum-guide.md): historical proposals and reported claims, not current operating instructions

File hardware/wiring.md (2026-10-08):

# 28BYJ-48 / ULN2003 wiring

The project owner confirmed two 28BYJ-48 motors with ULN2003 boards on 6 October 2026. The updated firmware uses four coil inputs per motor. **Rewire to this map before uploading the updated firmware.** The previous STEP/DIR/ENABLE table was incompatible with this hardware.

This is a proposed, explicit wiring revision matching `firmware/src/config.h`. Continuity, supply voltages, motor direction, actual wheel geometry and any external gears must be checked on the assembled robot before floor testing. Record those checks and calibration trials in the [hardware acceptance record](../docs/hardware-acceptance.md), following the [assembly sequence](../docs/assembly-guide.md).

The [selected power system](power-system.md) now specifies **5 V Olimex motor/ULN2003 kits, a Tenergy 31003 protected 7.4 V / 2200 mAh pack, a Pololu D24V22F5 regulator and a Tenergy TLP-4000 charger**. Use that parts list and power harness alongside this GPIO map. The selection does not establish what is already fitted to the robot.

## Motor connections

| ESP32 GPIO | Connection |
|---|---|
| 26 | Left ULN2003 IN1 |
| 27 | Left ULN2003 IN2 |
| 25 | Left ULN2003 IN3 |
| 33 | Left ULN2003 IN4 |
| 14 | Right ULN2003 IN1 |
| 13 | Right ULN2003 IN2 |
| 32 | Right ULN2003 IN3 |
| 23 | Right ULN2003 IN4 |
| GND | Both ULN2003 GND terminals and supply ground |

Connect each motor's five-wire plug to its driver board. Verify connector/coil order against the actual board; IN1 through IN4 are the labels on the board, not the physical order of GPIO numbers. Do not connect a coil directly to an ESP32 GPIO. The ULN2003 has no STEP/DIR/ENABLE interface; turning all four inputs off releases the motor.

The selected motors require a regulated 5 V rail. Check existing motor labels before reuse. A 7.4 V nominal battery can reach 8.4 V: it must not be connected directly to this motor rail. Follow the [power connection and USB programming procedure](power-system.md#power-connections) for the regulator and ESP32 board.

The default is nominally 4096 half-steps per geared motor output revolution, with a conservative 2000 microsecond interval. Manufacturing variants and additional axle/gearing change the effective steps per wheel revolution. These constants require calibration. The existing 65 mm wheel diameter and 150 mm track width are retained starting values, not newly verified measurements.

## Sensor and battery connections

| ESP32 GPIO | Connection |
|---|---|
| 5 | HC-SR04 TRIG |
| 18 | HC-SR04 ECHO through divider below |
| 21 | MPU6050 SDA (3.3 V logic) |
| 22 | MPU6050 SCL (3.3 V logic) |
| 35 | Battery voltage through divider below |
| GND | All sensor grounds and battery/supply ground |

Supply the ordinary HC-SR04 with regulated 5 V. Its 5 V Echo signal must be reduced before reaching GPIO18. The following divider produces approximately 3.0 V from a 5.0 V Echo signal:

```text
HC-SR04 ECHO ----- 2.2 kohm -----+----- GPIO18
                               |
                            3.3 kohm
                               |
                              GND
```

Use suitable 1% resistors and measure the signal/divider wiring before connecting the ESP32. This choice is for the ordinary 5 V HC-SR04; a different sensor variant requires checking its own specifications. Sources: [HC-SR04 pinout](https://learn.adafruit.com/ultrasonic-sonar-distance-sensors/pinouts), [ESP32-WROOM-32 electrical limits](https://documentation.espressif.com/esp32_wroom-32_datasheet_en.pdf).

The firmware's 2S battery measurement expects a divide-by-three network. At an 8.4 V pack voltage, GPIO35 sees approximately 2.8 V:

```text
Switched battery + ----- 20 kohm -----+----- GPIO35 (ADC1)
                                     |
                                  10 kohm
                                     |
                                    GND
```

Use suitable 1% resistors; verify the midpoint with a multimeter before connecting GPIO35. Never connect the pack directly to the GPIO. Check reported voltage against the meter and calibrate the divider/ADC as necessary. Battery percentage is a voltage-based estimate, not a calibrated fuel gauge. It is not battery protection or a low-voltage cutoff.

## Power and charging boundary

```text
Tenergy 31003 protected 2S pack
        |
  2 A DC fuse + keyed disconnect + DC-rated switch
        |
        +---- battery divider ---- GPIO35
        |
  Pololu D24V22F5 ---- regulated 5 V rail

All grounds share a common reference.
```

Part selection, fuse/harness requirements and the external charging procedure are specified in [power-system.md](power-system.md); physical assembly and measurements remain pending. Unplug the pack from the robot and charge it with the selected TLP-4000 through its matching insulated adapter. There is no onboard charging or simultaneous charge-and-run mode. The ESP32 USB connector and a buck converter do **not** constitute a 2S charging system.

## Bring-up checklist

1. With all power removed, verify each IN1..IN4 wire and common ground against the table.
2. Check motor labels, regulated supply voltage and divider ratios with a meter.
3. Raise the wheels. Command a short movement; STOP and BLE disconnection must turn all motor outputs off. Coil release does not mechanically brake a wheel or hold the robot on a slope.
4. Verify both physical directions. Adjust the firmware's per-side direction inversion configuration if a mirrored motor turns the wrong way.
5. At low speed on a clear, flat area, calibrate distance and turns. Record actual motor output gearing, external gear ratio, wheel diameter, track width and software version.
6. Verify sensor failure/timeout, stale data, obstacle stopping and stop latency before an educational demo. A front sensor does not protect the rear or sides during reverse/turning.

Native CAD files remain in this directory. Printable STL exports, neutral CAD exports, the axle/gear assembly mapping and measured mechanical drawings are still required for a reproducible release; this wiring revision does not supply those missing parts.

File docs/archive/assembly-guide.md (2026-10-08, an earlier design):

> Historical assembly guide preserved before the 8 October 2026 handoff revision. Dimensions, print settings, time estimates, performance targets and unverified procedures below are not current build instructions. Use the [current assembly guide](../assembly-guide.md), [wiring](../../hardware/wiring.md) and [power specification](../../hardware/power-system.md). Original text is retained for provenance.

# Educational Robot Assembly Guide

> **P1 hardware selection (8 October 2026):** build toward the [selected 5 V motor and protected battery system](../../hardware/power-system.md), using the [eight-input wiring map and sensing dividers](../../hardware/wiring.md). The previous STEP/DIR wiring is obsolete. Physical wiring, loading and CAD fit still require verification. STL filenames below are planned exports; those files are not yet supplied.

## Table of Contents
1. [Safety Information](#safety-information)
2. [Required Tools and Materials](#required-tools-and-materials)
3. [Component Overview](#component-overview)
4. [3D Printing Instructions](#3d-printing-instructions)
5. [Electronic Assembly](#electronic-assembly)
6. [Mechanical Assembly](#mechanical-assembly)
7. [Software Installation](#software-installation)
8. [Testing and Calibration](#testing-and-calibration)
9. [Troubleshooting](#troubleshooting)

---

## Safety Information

⚠️ **IMPORTANT SAFETY WARNINGS**

- **Adult supervision required** for children under 12
- **Soldering iron safety**: Use proper ventilation and safety equipment
- **Battery safety**: Never short circuit, puncture or dismantle the selected protected Li-ion pack
- **3D printer safety**: Ensure proper ventilation and temperature controls
- **Small parts warning**: Keep away from children under 3 years

### Required Safety Equipment
- Safety glasses for 3D printing and soldering
- Well-ventilated workspace
- Fire extinguisher nearby when working with batteries
- First aid kit accessible

---

## Required Tools and Materials

### Tools Needed
- [ ] 3D printer (minimum 200×200×200mm build volume)
- [ ] Soldering iron (25-40W) with fine tip
- [ ] Wire strippers
- [ ] Small Phillips head screwdriver
- [ ] Hot glue gun
- [ ] Multimeter (for testing)
- [ ] Computer with PlatformIO for the current firmware

### Consumables
- [ ] PLA filament (200g minimum) - White or colored
- [ ] TPU filament (50g) - For wheels (optional)
- [ ] 60/40 rosin-core solder
- [ ] Heat shrink tubing (various sizes)
- [ ] Jumper wires (male-to-female, 20cm)
- [ ] Hot glue sticks

### Hardware Components
- [ ] M3×12mm screws (8 pieces)
- [ ] M3×8mm screws (4 pieces)
- [ ] M3 nuts (12 pieces)
- [ ] M2×6mm screws (4 pieces) - For sensor mounting
- [ ] Motor-mount hardware selected after checking the delivered Olimex kit's M4 holes and bracket thickness; the historical M3 list is not a verified motor-mount specification

---

## Component Overview

### Electronic Components

Use the [selected bill of materials](../../README.md#-selected-bill-of-materials) and [power-system specification](../../hardware/power-system.md) as the common parts list. It selects two Olimex 5 V motor/ULN2003 kits, Tenergy 31003 protected pack, Pololu D24V22F5 and Tenergy TLP-4000, plus the specified harness, fuse, switch, capacitors and sensing dividers. Controller and sensor parts remain as listed in the project. Optional status LEDs are not controlled by the current firmware. A breadboard may be used for signals, but not for motor power distribution.

The old $36 electronic-parts subtotal omitted necessary items and is superseded. Current sourced prices are recorded once in the power specification; a complete delivered build cost remains pending.

### 3D Printed Components

| Part Name | Print Time | Infill | Support Required |
|---|---|---|---|
| Main Chassis | 4 hours | 20% | No |
| Battery Compartment | 2 hours | 15% | No |
| Sensor Mount | 1 hour | 25% | Yes |
| Wheel Hubs | 1 hour | 30% | No |
| Top Cover | 1.5 hours | 15% | No |

---

## 3D Printing Instructions

### Printer Settings
```
Layer Height: 0.2mm
Infill: 20% (cubic pattern)
Print Speed: 50mm/s
Nozzle Temperature: 210°C (PLA) / 230°C (TPU)
Bed Temperature: 60°C
Support: Only where specified
Brim: Recommended for better adhesion
```

### Pre-Print Checklist
- [ ] Bed properly leveled and clean
- [ ] Filament dry and properly loaded
- [ ] Nozzle clean and at correct temperature
- [ ] STL files verified in slicer software

### Part-Specific Instructions

**Main Chassis (chassis.stl)**
- Print orientation: Flat on largest surface
- No supports needed
- Critical dimension: the selected motor supplier lists **35 mm hole spacing and M4 holes**; 28 mm is the motor body diameter. Check the delivered kit and update/verify CAD before printing, as described in the [power/parts specification](../../hardware/power-system.md#mechanical-checks-and-acceptance).
- Post-processing: Light sanding of motor mount holes if needed

**Battery Compartment (battery-compartment.stl)**
- Print orientation: Opening facing up
- Add supports for overhangs >45°
- Test fit with actual battery before final assembly
- Critical: Ensure proper ventilation gaps

**Sensor Mount (sensor-mount.stl)**
- Print orientation: Mounting surface down
- Supports required for sensor bracket
- Angle: 15° downward for optimal detection
- Post-processing: Drill out mounting holes with 2mm bit

**Wheel Hubs (wheel-hub.stl) - 2 pieces**
- Print orientation: Flat surface down
- 30% infill for strength
- Critical: 5mm center hole must fit motor shaft exactly
- Test fit before removing supports

**Top Cover (top-cover.stl)**
- Print orientation: Largest surface down
- Include ventilation holes in design
- Optional: Print in transparent filament for LED visibility
- Post-processing: Sand edges for smooth fit

### Quality Check
After printing, verify:
- [ ] All holes are properly sized
- [ ] No warping or layer separation
- [ ] Smooth surfaces where components will mate
- [ ] No support material remaining in critical areas

---

## Electronic Assembly

### Step 1: Prepare the ESP32
1. **Test the ESP32** before assembly
   ```cpp
   // Upload this test code first
   void setup() {
     Serial.begin(115200);
     Serial.println("ESP32 Test - Success!");
   }
   void loop() {
     delay(1000);
   }
   ```

2. **Solder header pins** (if not pre-installed)
   - Use 2.54mm pitch headers
   - Ensure pins are straight and properly seated
   - Test continuity with multimeter

### Step 2: Motor Driver Preparation
1. **Check ULN2003 boards**
   - Inspect IN1..IN4, motor connector and power terminal labels
   - With the wheels raised, verify the half-step coil sequence using the updated firmware

2. **Verify the supply rating**
   - Read the motor voltage label and the driver board documentation
   - Follow [hardware/wiring.md](../../hardware/wiring.md); do not infer board jumper changes from a generic IC datasheet

### Step 3: Sensor Preparation

**HC-SR04 Ultrasonic Sensor**
Connect Echo through the divider in [the wiring guide](../../hardware/wiring.md) before this test. Ordinary HC-SR04 Echo is 5 V logic.
1. Test sensor functionality:
   ```cpp
   const int trigPin = 5;
   const int echoPin = 18;
   
   void setup() {
     Serial.begin(115200);
     pinMode(trigPin, OUTPUT);
     pinMode(echoPin, INPUT);
   }
   
   void loop() {
     digitalWrite(trigPin, LOW);
     delayMicroseconds(2);
     digitalWrite(trigPin, HIGH);
     delayMicroseconds(10);
     digitalWrite(trigPin, LOW);
     
     long duration = pulseIn(echoPin, HIGH);
     float distance = duration * 0.034 / 2;
     
     Serial.printf("Distance: %.2f cm\n", distance);
     delay(500);
   }
   ```

**MPU6050 IMU**
1. Verify I2C communication:
   ```cpp
   #include <Wire.h>
   
   void setup() {
     Serial.begin(115200);
     Wire.begin();
     
     Wire.beginTransmission(0x68); // MPU6050 address
     if (Wire.endTransmission() == 0) {
       Serial.println("MPU6050 found!");
     } else {
       Serial.println("MPU6050 not found!");
     }
   }
   ```

### Step 4: Power System Assembly

**Buck Converter Setup**
1. **Use the fixed-output Pololu D24V22F5**; there is no voltage-adjustment potentiometer
2. **Measure the output before connecting electronics**, then test at the specified input voltages and 1.2 A design load
3. **Fit the specified capacitors and power harness**, then check actual motor-start transients and regulator temperature using the [acceptance procedure](../../hardware/power-system.md#mechanical-checks-and-acceptance)

**Battery Connection**
1. **Fit the keyed J1 harness** specified in the power guide, with verified polarity and insulated contacts
2. **Fit F1, a 2 A DC-rated fuse**, close to the pack positive output; verify fuse, holder, wire rating and startup behavior
3. **Test polarity** multiple times before connecting to circuit

### Step 5: Main Circuit Assembly

**Breadboard Layout**
```
Row 1: ESP32 (pins 1-19)
Row 8: ESP32 (pins 20-38)
Row 15: Motor Driver 1 (Left)
Row 20: Motor Driver 2 (Right)
Row 25: Sensors and power distribution
```

**Connection Table**
| ESP32 Pin | Connection | Component |
|---|---|---|
| 5 | Trig Pin | HC-SR04 |
| 18 | Echo through 2.2 kohm / 3.3 kohm divider | HC-SR04 |
| 21 | SDA | MPU6050 |
| 22 | SCL | MPU6050 |
| 26 | IN1 | Left ULN2003 |
| 27 | IN2 | Left ULN2003 |
| 25 | IN3 | Left ULN2003 |
| 33 | IN4 | Left ULN2003 |
| 14 | IN1 | Right ULN2003 |
| 13 | IN2 | Right ULN2003 |
| 32 | IN3 | Right ULN2003 |
| 23 | IN4 | Right ULN2003 |
| 35 | Battery through 20 kohm / 10 kohm divider | 2S pack sensing |
| 3.3V | VCC | MPU6050 |
| Regulated 5V | VCC | HC-SR04 and selected 5 V motor rail |
| GND | GND | All components |

### Step 6: Wiring Best Practices

1. **Use consistent color coding:**
   - Red: +5V power
   - Black: Ground
   - Yellow: Signal wires
   - Blue: I2C (SDA/SCL)

2. **Secure all connections:**
   - Twist and solder wire joints
   - Cover with heat shrink tubing
   - Test continuity before powering on

3. **Cable management:**
   - Route wires away from moving parts
   - Leave service loops for future maintenance
   - Use cable ties or adhesive mounts

---

## Mechanical Assembly

### Step 1: Motor Installation

1. **Prepare motor mounts:**
   - Test fit motors in chassis holes
   - File or sand if too tight (common with PLA shrinkage)

2. **Install motors:**
   - Insert motors from inside chassis
   - Use fasteners that match the actual mounting holes and measured bracket thickness; do not assume the historical M3×12mm hardware fits the selected kit
   - Ensure motor shafts are parallel and level

3. **Attach wheel hubs:**
   - Press fit hubs onto motor shafts
   - Ensure tight fit (use small amount of threadlocker if needed)
   - Test rotation - should be smooth with no wobble

### Step 2: Sensor Mounting

1. **Install ultrasonic sensor:**
   - Mount sensor bracket at 15° downward angle
   - Secure with M2×6mm screws
   - Ensure clear line of sight forward

2. **Install IMU:**
   - Mount as close to robot center as possible
   - Ensure flat, stable mounting surface
   - Orient X-axis pointing forward

### Step 3: Electronic Integration

1. **Install breadboard:**
   - Use double-sided foam tape
   - Position for easy access to connections
   - Ensure no interference with moving parts

2. **Route wiring:**
   - Keep power wires separate from signal wires
   - Secure with small cable ties
   - Leave enough slack for any chassis flexing

### Step 4: Battery Installation

1. **Test battery compartment fit:**
   - Battery should slide in easily but not rattle
   - Adjust compartment size if needed with file or sandpaper

2. **Install power connections:**
   - Make the battery connector accessible for removal and external charging with a compatible charger
   - Follow the [power and charging boundary](../../hardware/wiring.md#power-and-charging-boundary); no onboard charger has been validated
   - Install main power switch in accessible location
   - Add LED power indicator

### Step 5: Final Assembly

1. **Install top cover:**
   - Ensure all wires are properly routed
   - Check that no components interfere with cover
   - Secure with M3×8mm screws

2. **Attach wheels (if using TPU printed wheels):**
   - Press fit onto wheel hubs
   - Ensure wheels are aligned and balanced
   - Test rotation and ground contact

---

## Software Installation

### Step 1: Development Environment Setup

**PlatformIO**
1. Install Visual Studio Code
2. Install PlatformIO extension
3. Clone the repository and open the `firmware` folder
4. Check the wiring against [hardware/wiring.md](../../hardware/wiring.md) before powering the motors

The supported project is the multi-file application in `firmware/src`, built with `firmware/platformio.ini`. The archived Arduino sketch uses the old driver assumptions and is not an upload target for this revision.

### Step 2: Library Installation

PlatformIO installs the pinned platform and libraries from `platformio.ini`. From the `firmware` directory, build before connecting the robot:

```bash
pio run
```

### Step 3: Code Upload

1. **Connect ESP32** via USB cable
2. **Check the ESP32 board and serial port** against the PlatformIO configuration
3. **Upload firmware:**
   ```bash
   pio run --target upload
   ```

### Step 4: Initial Configuration

1. **Open Serial Monitor** (115200 baud)
2. **Verify startup messages:**
   ```
   E-Bug Educational Robot Starting...
   Version: 1.0.0
   Motor control initialized
   Sensor management... OK
   BLE communication... OK
   Navigation system... OK
   Robot ready for commands...
   ```

3. **Test basic functions:**
   - BLE advertising should start
   - Sensors should report valid readings
   - Motors should respond to test commands

---

## Testing and Calibration

### Step 1: System Health Check

**Power System Test**
- [ ] Battery voltage: 6.4-8.4 V operating target; recharge before reaching the specified 6.0 V endpoint
- [ ] 5 V rail: 4.8-5.2 V at the design test load and during actual operation
- [ ] Validate the calculated 1.2 A output-load budget, startup behavior and fuse choice; record actual idle/moving current instead of assuming the old <800 mA figure

**Sensor Test**
- [ ] Ultrasonic: Range 2-400cm, stable readings
- [ ] IMU: No error messages, reasonable temperature
- [ ] BLE: Discoverable from mobile device

**Motor Test**
- [ ] Left motor: Smooth rotation both directions
- [ ] Right motor: Smooth rotation both directions
- [ ] Synchronization: Both motors start/stop together

### Step 2: Movement Calibration

**Distance Calibration**
1. Place robot on smooth, flat surface
2. Mark starting position
3. Command 100cm forward movement
4. Measure actual distance traveled
5. Check `STEPS_PER_REV` and `WHEEL_DIAMETER` in `firmware/src/config.h` against the measured gearing and wheel travel

Use the current motor/wheel configuration in `firmware/src/config.h`; account for any external gears. The old 200-pulse STEP/DIR calibration does not apply to the ULN2003 half-step driver.

**Rotation Calibration**
1. Mark robot's starting orientation
2. Command 90° rotation
3. Measure actual rotation angle
4. Adjust `ROBOT_WIDTH` in `firmware/src/config.h` only after measuring the actual wheel track and calibrating wheel travel

**Surface Adaptation**
- Test on different surfaces (tile, carpet, wood)
- Note any variations in accuracy
- Consider implementing surface-specific calibration

### Step 3: Mobile App Integration

**BLE Connection Test**
1. Install mobile app on test device
2. Ensure robot is discoverable
3. Test connection establishment (<5 seconds)
4. Verify bidirectional communication

**Programming Interface Test**
1. Create simple forward movement program
2. Verify program execution matches expectation
3. Test all programming blocks
4. Confirm telemetry data accuracy

**Range Testing**
1. Test BLE range in open space (should reach 12m)
2. Test through common obstacles (walls, furniture)
3. Verify graceful handling of connection loss

### Step 4: Educational Validation

**Age Group Testing (if possible)**
1. Test with children aged 7-12
2. Observe ease of use and engagement
3. Note any confusion points or improvements needed
4. Document successful completion rates

**Curriculum Alignment**
1. Verify learning objectives are met
2. Test progressive difficulty curve
3. Ensure age-appropriate complexity
4. Validate the supervised operating procedure and document its limits

---

## Troubleshooting

### Common Assembly Issues

**Problem: Motors don't turn smoothly**
- Check motor mounting screws aren't over-tightened
- Verify motor driver connections
- Test motor independently of robot chassis
- Check for mechanical interference

**Problem: Inconsistent sensor readings**
- Verify sensor power supply (5V for HC-SR04, 3.3V for MPU6050)
- Check wire connections for intermittent contact
- Ensure sensors are firmly mounted
- Test in different environments to rule out interference

**Problem: BLE connection fails**
- Verify ESP32 is programmed correctly
- Check for correct BLE UUIDs in code
- Ensure mobile device BLE is enabled
- Try restarting both devices

**Problem: Battery drains quickly**
- Check for short circuits with multimeter
- Verify buck converter efficiency
- Look for unnecessary current draws
- Consider battery capacity vs. expected runtime

### Performance Issues

**Problem: Robot movements are jerky**
- Adjust stepper motor speed (increase delay values)
- Check power supply stability under load
- Verify mechanical assembly smoothness
- Verify the motor supply rating and ULN2003 coil wiring; this board has no adjustable STEP/DIR driver current setting

**Problem: Navigation seems erratic**
- Keep the robot still and level during startup gyro calibration; the MPU6050 does not provide a compass heading
- Check ultrasonic sensor mounting angle
- Verify obstacle detection thresholds
- Test navigation algorithm in controlled environment

### Software Issues

**Problem: Upload fails**
- Check USB cable and connections
- Verify correct board selection in IDE
- Try different USB port
- Hold BOOT button during upload if needed

**Problem: Sensor data appears incorrect**
- Verify pin assignments match code
- Check sensor orientation (especially IMU)
- Test sensors individually with simple code
- Verify I2C address for MPU6050 (usually 0x68)

### Getting Help

If you encounter issues not covered here:

1. **Check GitHub Issues** for similar problems
2. **Review serial monitor output** for error messages
3. **Test components individually** to isolate problems
4. **Document your specific setup** when asking for help
5. **Include photos** of wiring and assembly if needed

**Support Channels:**
- GitHub Issues: Technical problems and bugs
- Email: ayman.ouchker@outlook.com
- Documentation: Complete guides and tutorials

---

## Appendix

### A. Bill of Materials with Supplier Links
[Include specific part numbers and recommended suppliers]

### B. 3D Printing Troubleshooting
[Common 3D printing issues specific to these parts]

### C. Alternative Component Options
[Substitute components for different budgets or availability]

### D. Advanced Modifications
[Optional enhancements for advanced users]

---

**Assembly Time:** 4-6 hours (experienced) / 8-12 hours (beginner)  
**Difficulty Level:** Intermediate (requires basic soldering skills)  
**Age Recommendation:** 14+ for assembly, 7+ for use

*P1 motor/power selection updated: 8 October 2026. Mechanical dimensions and historical performance estimates remain subject to physical validation.*

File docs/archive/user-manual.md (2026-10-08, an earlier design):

> **Historical planning material — archived 8 October 2026.** Use the [current user manual](../user-manual.md) for this build. This preserved version mixes proposed features, historical claims and implemented behavior; it is not an operating or release specification. Reported research figures remain subject to [reconciliation](../research-reconciliation.md), not revalidated by this archive.

# Educational Robot User Manual

> **Prototype status:** use the updated [wiring and power guide](../../hardware/wiring.md) before operating this hardware revision. The repository supplies a DIY prototype, not a packaged kit with an included charger. Some lessons/features below are historical design material and remain pending implementation or validation; see [P1 completion status](../p1-status.md).

## Quick Start Guide

### Welcome to Your Educational Robot! 🤖

Congratulations on your new educational robot! This guide will help you get started with programming and controlling your robot using the mobile app.

**Required for operation:**
- An assembled and checked robot matching the current wiring
- The [selected protected 7.4 V battery and fixed 5 V regulator](../../hardware/power-system.md), with the checked power harness
- The selected Tenergy TLP-4000 external charger and matching insulated pack adapter
- An Android 7.0+ phone with Bluetooth Low Energy running the matching app version

The ESP32 USB connector does not charge the 2S battery pack. The charger is a separate purchase, and charging takes place with the pack disconnected from the robot. The [power guide](../../hardware/power-system.md#charging-procedure) specifies the procedure. The reference motor voltage is 5 V; check existing parts against the selected models before use.

## Current P1 operation

Updated 8 October 2026. This section describes the current app and matching firmware. The curriculum and concept screens later in this manual also describe planned features; use this section as the operating reference for P1.

| Available block | Parameter and behavior |
|---|---|
| Move Forward / Move Backward | Whole centimetres, 0–500; default 100 |
| Turn Left / Turn Right | Whole degrees, 0–360; default 90 |
| Wait | Whole **milliseconds**, 0–60000; default 1000. Enter **2000** for two seconds. Wait has no child blocks. |
| If Distance < | Threshold in whole centimetres, 2–400; default 20. Runs its child blocks only when a fresh, valid distance is strictly below the threshold. |
| Stop | Stops motion and disables autonomous mode. Later blocks in the program can issue new movement commands. |
| Auto Navigate | Runs an autonomous activity for three seconds, then stops before the next block. Sensor or motion faults fail the run. |

The toolbox exposes these blocks progressively by level. Zero-valued movement and turn commands are no-ops. The front sensor cannot check rear or side clearance; supervise reverse movement and turns.

1. Connect from the app's **Connect → Bluetooth** screen. Wait for the connection to succeed.
2. **Hold and drag** a toolbox block into the workspace. Tap a workspace block's heading to edit its parameter.
3. Arrange top-level blocks from top to bottom. Drop child blocks inside an **If Distance <** block to make them conditional; children execute in their displayed order.
4. Tap **Run** to open Robot Execution, then tap **Start** to execute. Completion waits for the robot's acknowledgements; it does not verify physical wheel displacement.
5. Tap **Stop** on Robot Execution to cancel the whole run. Going back or backgrounding the app also cancels it. If STOP is unconfirmed, the app attempts to disconnect Bluetooth to trigger the firmware's stop behavior. Check that the robot has stopped; use the physical power disconnect if needed. Reconnect only after checking the robot.

**Available in the P2 persistence update:** named **Save** and **Open**, plus practice checks after successful robot execution. Saving alone does not complete a lesson. See [Saving and Loading Programs](#-saving-and-loading-programs) and [P2 status](../p2-status.md).

**Still planned:** Repeat/While loops, If/Else, general comparison/math blocks, standalone distance/battery blocks, joystick/speed control, sharing/export, Wi-Fi operation and iOS release support. Historical lessons using those features remain design material.

---

## Table of Contents

1. [Safety First](#safety-first)
2. [Getting Started](#getting-started)
3. [Mobile App Guide](#mobile-app-guide)
4. [Programming Basics](#programming-basics)
5. [Learning Levels](#learning-levels)
6. [Advanced Features](#advanced-features)
7. [Maintenance](#maintenance)
8. [Troubleshooting](#troubleshooting)
9. [Educational Activities](#educational-activities)

---

## Safety First

### 🛡️ Important Safety Rules

**Before You Start:**
- Always have an adult nearby when first learning
- Keep robot away from stairs and high surfaces
- Don't use near water or wet surfaces
- Never disassemble the robot
- Charge the disconnected pack with a charger specified for its chemistry, cell count and connector/polarity; follow the pack and charger manufacturer's instructions

**During Use:**
- Clear the play area of obstacles
- Keep fingers away from moving wheels
- Stop robot if it makes unusual sounds
- Don't block the robot's sensors
- Take breaks every 30 minutes

**Battery Safety:**
- Charge in open, well-ventilated area
- Never leave charging unattended
- Unplug when fully charged
- Stop using if battery swells or gets hot

---

## Getting Started

### Step 1: First Power-On

1. **Check the assembly and power wiring** against the [current hardware guide](../../hardware/wiring.md).
2. **Connect the correctly rated supply** using the switch and connector fitted to your verified assembly.
3. **Turn on the robot** and check its startup messages using the serial monitor, then look for **E-Bug ESP32** in the app's Bluetooth scan.
4. **Check the configured battery telemetry** after connection. Its percentage is meaningful only after the divider and pack voltage settings have been verified.

The current firmware releases the motor coils at startup and waits for an explicit movement command. It does not implement the previously described motor self-test or colored power, connection and battery LED indications.

### Step 2: Download the App

**For Android:**
1. Build the matching Android test APK using the [mobile app instructions](../../mobile-app/README.md), or obtain that same build from the project author
2. Enable "Install from unknown sources" in Settings
3. Install the Educational Robot app
4. Grant Bluetooth and Location permissions

**For iPhone/iPad:**
- Coming soon! Check our website for updates

### Step 3: Connect Your Robot

1. **Open the app** and select **Connect → Bluetooth**, then scan for devices
2. **Make sure Bluetooth is on** on your phone/tablet
3. **Look for "E-Bug ESP32"** in the device list
4. **Tap to connect** and wait for the app to confirm the connection
5. **You're ready to program!** 🎉

---

## Mobile App Guide

### Main Screen Overview

The following is a historical concept sketch; use [Current P1 operation](#current-p1-operation) for available controls and blocks.

```
┌─────────────────────────────────┐
│  🤖 Educational Robot           │
│  ┌─────────┐    ┌─────────────┐ │
│  │Connected│    │ Battery: 85%│ │
│  └─────────┘    └─────────────┘ │
│                                 │
│  ┌─── Programming Area ────────┐│
│  │                             ││
│  │  Drag blocks here to        ││
│  │  create your program        ││
│  │                             ││
│  └─────────────────────────────┘│
│                                 │
│  [▶ Run] [⏹ Stop] [💾 Save]    │
│                                 │
│  ┌─── Block Palette ──────────┐ │
│  │ 🔄 Move  🔁 Turn  ⏱ Wait   │ │
│  │ 🔀 If    🔂 Loop  📡 Sensor │ │
│  └─────────────────────────────┘ │
└─────────────────────────────────┘
```

### Key Features

**🔗 Connection Status**
- Green: Connected and ready
- Yellow: Connecting...
- Red: Disconnected - check robot power and Bluetooth

**🔋 Battery Monitor**
- Shows robot's current battery level
- Updates every few seconds
- Warning appears when low

**📱 Real-Time Data**
- Distance to obstacles
- Robot's direction (compass)
- Internal temperature
- Connection quality

---

## Programming Basics

### Understanding Blocks

Your robot understands different types of commands, represented as colorful blocks:

#### 🔄 Movement Blocks (Blue)
- **Move Forward**: Makes robot go straight
- **Move Backward**: Makes robot go in reverse  
- **Turn Left**: Rotates robot left
- **Turn Right**: Rotates robot right

#### ⏱ Timing Blocks (Orange)
- **Wait**: Pause for a whole number of milliseconds; 1000 ms is one second
- **Repeat**: Planned; unavailable in P1

#### 🔀 Logic Blocks (Purple)
- **If Distance <**: Run child blocks when a fresh, valid distance is below the threshold
- **If/Else**: Planned; unavailable in P1

#### 📡 Sensor Blocks (Purple)
- Standalone **Distance** and **Battery** blocks are planned. P1 provides the **If Distance <** condition and the Sensors screen.

### Creating Your First Program

**Let's make the robot move in a square:**

1. **Hold and drag a "Move Forward" block** to the programming area
2. **Set the distance** to 50 cm by tapping the block's heading
3. **Add a "Turn Right" block** below it
4. **Set the angle** to 90 degrees
5. **Repeat these steps** 3 more times
6. **Tap the "Run" button** ▶ to open Robot Execution
7. **Tap "Start"** to begin; use **Stop** to cancel the run

The program requests a square path. Verify motor direction and calibrate distances and angles on the actual robot; open-loop motor steps do not guarantee a perfect square.

### Block Snapping

- **Drop inside If Distance <** to attach a child block; the drop area highlights while it accepts a block
- **Drag a child into another condition** to move it there
- **Drag a child back into the workspace** to make it a top-level block
- **Use Clear** to remove the whole workspace; individual trash-can deletion is not implemented

---

## Learning Levels

The following four lesson outlines are historical curriculum material. The current app exposes five level labels, with only the blocks listed in [Current P1 operation](#current-p1-operation) implemented. References below to loops, comparisons and If/Else describe planned lessons.

### 🟢 Level 1: Basic Movement (Ages 7-8)
**What You'll Learn:**
- How to make the robot move forward and backward
- How to turn left and right
- How to create simple shapes

**Available Blocks:**
- Move Forward/Backward
- Turn Left/Right
- Basic timing

**Sample Challenge:**
*"Make your robot draw a triangle by moving and turning!"*

**Success Criteria:**
- Complete 3 basic movement programs
- Create a simple shape (triangle, square, or star)
- Understand cause and effect of each block

---

### 🟡 Level 2: Sequences and Timing (Ages 8-10)
**What You'll Learn:**
- How to create longer sequences
- Using wait blocks for timing
- Making patterns and dances

**New Blocks Added:**
- Wait (with time setting)
- Repeat (basic loops)

**Sample Challenge:**
*"Program your robot to do a dance with moves and pauses!"*

**Success Criteria:**
- Create programs with 10+ blocks
- Use timing to create rhythmic patterns
- Combine movement and waiting effectively

---

### 🟠 Level 3: Sensors and Decisions (Ages 9-11)
**What You'll Learn:**
- How robots can "see" obstacles
- Making decisions based on sensor data
- Creating reactive behaviors

**New Blocks Added:**
- If (conditional logic)
- Distance sensor reading
- Compare blocks (greater than, less than)

**Sample Challenge:**
*"Make your robot avoid obstacles by checking distance!"*

**Success Criteria:**
- Use sensors to make decisions
- Create programs that react to environment
- Understand conditional logic

---

### 🔴 Level 4: Autonomous Behavior (Ages 10-12)
**What You'll Learn:**
- Complex logic and nested conditions
- Autonomous navigation
- Advanced programming concepts

**New Blocks Added:**
- If/Else (full conditional logic)
- Nested loops
- Advanced sensor combinations
- Autonomous mode

**Sample Challenge:**
*"Program your robot to explore a room completely on its own!"*

**Success Criteria:**
- Create complex, multi-step programs
- Implement autonomous behaviors
- Understand advanced programming concepts

---

## Advanced Features

### 📊 Telemetry Dashboard

Access real-time robot data by tapping the "Data" button:

**Distance Sensor**
- Shows exact distance to nearest obstacle
- Range: 2-400 centimeters
- Updates 10 times per second

**Compass/Heading**
- Shows which direction robot is facing
- 0° = North, 90° = East, 180° = South, 270° = West
- Useful for navigation programs

**System Health**
- Battery percentage and voltage
- Internal temperature (should be 20-40°C)
- Connection signal strength

### 🎮 Manual Control Mode

Sometimes you want to drive the robot directly:

1. **Tap "Manual Control"** in the main menu
2. **Use on-screen joystick** or arrow buttons
3. **Adjust speed** with the slider
4. **Perfect for** testing movements and exploring

### 💾 Saving and Loading Programs

**To Save a Program:**
1. Create your program with blocks
2. Tap the "Save" button 💾
3. Enter a name (1–64 characters) and tap "Save program"
4. Confirm replacement if the name is already used, or cancel and use a new name to keep both copies. Names are case-insensitive.

The program's current level, parameters, positions and nested blocks are stored on this device. The library holds up to 50 named programs, each with up to 100 blocks. Saving an empty draft is allowed. Save after editing; unsaved changes are not automatically restored after closing the app. Uninstalling the app or clearing its data removes these local programs. There is no export or cloud backup yet.

**To Load a Program:**
1. Tap "Open" in the Code screen
2. Select a saved program; its name, lesson and save time are shown
3. If prompted about unsaved changes, cancel to save them first or confirm replacement
4. Continue editing in the program's saved level. That level must be unlocked.

"Clear" asks before removing workspace blocks and leaves saved programs intact. Switching tabs retains the current workspace. A failed save shows an error and keeps the workspace available for retry.

**Robot practice progress:** the progress bar counts five practice checks, from 0% to 100%. Checks are recorded only after the whole program succeeds and the final STOP is confirmed. Follow the requirement displayed above the editor:

| Level | Practice check |
| --- | --- |
| 1 | Execute a nonzero move or turn. |
| 2 | Execute a nonzero move or turn and a nonzero Wait. |
| 3 | Execute a move, turn, Stop or Auto Navigate inside a true If Distance condition. |
| 4 | Complete the three-second Auto Navigate block. |
| 5 | Complete Auto Navigate and the conditional response described for level 3 in one run. |

Skipped branches, zero-valued moves/waits, failures and cancelled runs do not earn these checks. Completing a check unlocks the next lesson; select it on Home. Earlier versions awarded badges from block presence alone: their unlocked lesson access is retained, but their badges are not counted as executed practice. These checks record software execution, not measured wheel travel, course accuracy or educational effectiveness; teachers still assess learning and physical behavior.

**Sharing Programs:**
- File and QR export are not implemented
- Share screenshots of your block programs
- Show friends your robot's movements!

### 🏆 Achievement System

The detailed achievement badges below are planned. The implemented app currently records only the five robot practice checks described above:

**First Steps**
- ✅ First successful program
- ✅ First shape creation
- ✅ First sensor use

**Getting Creative**
- ✅ Program with 20+ blocks
- ✅ Use all block types
- ✅ Create original dance

**Master Programmer**
- ✅ Complete all level challenges
- ✅ Create autonomous behavior
- ✅ Help someone else learn

---

## Maintenance

### Daily Care

**After Each Use:**
- Turn off the robot to save battery
- Put robot in a safe place away from edges
- Clean any dust from sensors with soft cloth

**Weekly Maintenance:**
- Check all connections are secure
- Clean wheels if they've collected debris
- Charge battery if below 50%

### Battery Care

**Charging Best Practices:**
- Stop and recharge around the selected 6.4 V operating target, using a meter until telemetry is calibrated; the firmware does not automatically stop on low battery
- Follow the [external charging procedure](../../hardware/power-system.md#charging-procedure) with the pack removed from the robot
- Follow the external charger's completion indication and instructions; the robot has no implemented charging-status LED
- Follow the pack manufacturer's storage guidance; the selected pack's specification recommends about half charge for long storage
- Replace battery if it swells or won't hold charge

**Battery Runtime:**
- Runtime with the selected pack and updated motor driver has not been measured. Record it during supervised testing; the previous 90/60/45-minute figures are not verified expectations for this revision.

### Storage

**Short-term (1-7 days):**
- Turn off robot
- Store on flat surface away from edges
- Room temperature location

**Long-term (weeks/months):**
- Prepare the battery for storage according to its manufacturer's instructions
- Remove battery and store separately
- Keep in original box or safe location
- Avoid extreme temperatures

---

## Troubleshooting

### Connection Problems

**🔴 Can't find robot in app:**
1. Check the robot's supply/switch and startup messages; no specific robot LED indicates readiness in this firmware
2. Check Bluetooth is enabled on your device
3. Move closer to robot (within 3 meters)
4. Restart the app
5. Try turning robot off and on again

**🔴 Connection keeps dropping:**
1. Check robot battery level (charge if low)
2. Move away from WiFi routers and other devices
3. Close other Bluetooth apps
4. Keep device closer to robot during use

### Programming Issues

**🔴 Robot doesn't move as expected:**
1. Check for obstacles in the path
2. Make sure robot is on flat, smooth surface
3. Verify your program logic step-by-step
4. Try simpler movements first

**🔴 Blocks won't snap together:**
1. Hold a toolbox block before dragging it into the workspace
2. Drop onto the highlighted area inside an If Distance < block to nest it
3. Wait and movement blocks cannot contain children; a block cannot be nested inside itself or its descendants
4. Use landscape mode for more space

**🔴 Program stops unexpectedly:**
1. Check if obstacle was detected (safety feature)
2. Verify battery isn't too low
3. Look for error messages in the app
4. Try breaking program into smaller parts

### Hardware Issues

**🔴 Robot makes unusual sounds:**
1. Turn off robot immediately
2. Check for objects caught in wheels
3. Look for loose screws or parts
4. Contact support if sounds continue

**🔴 Sensors seem inaccurate:**
1. Clean sensor lenses with soft, dry cloth
2. Check sensor isn't blocked by decorations
3. Test in different lighting conditions
4. Restart robot to recalibrate

**🔴 LED indicators not working:**
The current firmware does not drive status LEDs. Any LED built into the ESP32, motor driver or external charger follows that component's own behavior; use the app's connection status, serial messages and verified battery measurements to check the robot.

### Getting Help

**When to Contact Support:**
- Hardware damage or unusual behavior
- Persistent connection problems
- Safety concerns
- Questions not covered in this manual

**Support Channels:**
- 📧 Email: ayman.ouchker@outlook.com
- 💬 GitHub Issues: Report bugs and request features

**Before Contacting Support:**
1. Try the troubleshooting steps above
2. Note exactly what you were doing when the problem occurred
3. Check what version of the app you're using
4. Have your robot's serial number ready (found on bottom sticker)

---

## Educational Activities

### 🎯 Structured Learning Activities

#### Activity 1: Robot Dance Party (Level 1-2)
**Age Group:** 7-10 years  
**Time:** 15-20 minutes  
**Learning Goals:** Sequencing, timing, creativity

**Instructions:**
1. Choose your favorite song
2. Program your robot to "dance" to the music
3. Use forward, backward, and turning moves
4. Add wait blocks to match the rhythm
5. Show your dance to family or friends!

**Extensions:**
- Create different dances for different types of music
- Program multiple robots to dance together
- Add LED patterns (if available)

#### Activity 2: Obstacle Course Challenge (Level 3)
**Age Group:** 9-12 years  
**Time:** 30-45 minutes  
**Learning Goals:** Problem-solving, sensor use, debugging

**Setup:**
- Create a simple course with boxes, books, or toys
- Leave clear paths between obstacles
- Make sure robot can fit through gaps

**Instructions:**
1. Program robot to navigate through course
2. Use distance sensor to detect obstacles
3. Add decision-making: if obstacle is close, turn
4. Test and adjust your program
5. Time how fast your robot completes the course!

**Extensions:**
- Make the course more complex
- Program robot to find specific objects
- Create a maze-solving challenge

#### Activity 3: Room Mapping Explorer (Level 4)
**Age Group:** 10+ years  
**Time:** 45-60 minutes  
**Learning Goals:** Autonomous behavior, advanced logic

**Instructions:**
1. Choose a safe room or large area
2. Program robot to explore systematically
3. Use sensors to avoid walls and furniture
4. Create a pattern: wall-following or grid search
5. Challenge: Can your robot return to start position?

**Extensions:**
- Draw a map of where the robot went
- Program robot to find the largest open space
- Create a "search and rescue" scenario

### 🏫 Classroom Integration Ideas

#### Mathematics Integration
**Geometry and Measurement:**
- Program robots to draw geometric shapes
- Calculate perimeter and area of robot's path
- Explore angles through turning commands
- Practice measurement using distance moves

**Example Lesson Plan:**
```
Topic: Understanding Perimeter
1. Review perimeter concept (5 minutes)
2. Program robot to trace rectangle (15 minutes)
3. Measure actual vs. programmed distances (10 minutes)
4. Calculate and verify perimeter (10 minutes)
5. Challenge: Create shape with specific perimeter (15 minutes)
```

#### Science Integration
**Physics Concepts:**
- Distance, speed, and time relationships
- Forces and motion through robot movement
- Sensor technology and measurement
- Energy and battery concepts

**Programming as Scientific Method:**
- Hypothesis: "Robot will move exactly 100cm"
- Experiment: Program and test movement
- Observation: Measure actual distance
- Analysis: Calculate error and adjust
- Conclusion: Understand real-world vs. theory

#### Language Arts Integration
**Storytelling with Robots:**
- Create stories where robot is the main character
- Program robot to act out story scenes
- Write step-by-step instructions (technical writing)
- Present robot programs to class (public speaking)

### 👨‍👩‍👧‍👦 Family Learning Activities

#### Parent-Child Programming Sessions
**For Parents New to Programming:**

**Session 1: Introduction (30 minutes)**
- Learn together - no pressure to know everything
- Start with simple forward/backward movements
- Celebrate small successes
- Let child teach you what they discover

**Session 2: Problem Solving (45 minutes)**
- Give robot a "mission" (reach a toy, avoid obstacles)
- Work together to solve the challenge
- Discuss different approaches
- Learn from "failures" - they're learning opportunities!

**Session 3: Creative Expression (60 minutes)**
- Let child lead the programming
- Ask questions: "What do you think will happen?"
- Encourage experimentation
- Document creations with photos/videos

#### Sibling Collaboration Projects
**For Multiple Children:**

**Relay Programming:**
- Each child programs one part of a longer sequence
- Robot must complete all parts successfully
- Teaches planning and teamwork
- Great for different skill levels

**Robot Olympics:**
- Create different "events" (speed, accuracy, creativity)
- Each child programs robot for their event
- Friendly competition with scoring
- Celebrate all achievements

### 🎓 Assessment and Progress Tracking

#### Self-Assessment Questions
**For Students to Ask Themselves:**

**After Each Programming Session:**
- What did I learn today?
- What was challenging and how did I solve it?
- What would I like to try next time?
- How can I help someone else learn this?

**Weekly Reflection:**
- What programming concepts do I understand now?
- What real-world problems could robots help solve?
- How has my problem-solving improved?
- What questions do I still have?

#### Portfolio Development
**Document Learning Journey:**

**Week 1-2: First Steps**
- Screenshots of first programs
- Photos of robot completing tasks
- Written description of what was learned

**Week 3-4: Building Complexity**
- More sophisticated program examples
- Problem-solving strategies discovered
- Collaboration experiences with others

**Week 5-6: Advanced Projects**
- Original robot challenges created
- Teaching moments with younger children
- Connections made to other subjects

#### Progress Indicators
**Observable Signs of Learning:**

**Beginner (Level 1-2):**
- Can create simple sequential programs
- Understands cause-and-effect of commands
- Shows persistence when programs don't work
- Expresses excitement about robot's movements

**Intermediate (Level 3):**
- Uses logical thinking to solve problems
- Incorporates sensor feedback into programs
- Explains thinking process to others
- Creates original challenges

**Advanced (Level 4):**
- Designs complex, multi-step solutions
- Debugs programs systematically
- Helps others learn programming concepts
- Makes connections to real-world applications

---

## Appendices

### Appendix A: Block Reference Guide

**Current movement/Wait parameters and historical planned block examples:** only the blocks in [Current P1 operation](#current-p1-operation) are available. Repeat, If/Else and standalone sensor blocks below are planned.

#### Movement Blocks
```
Move Forward [distance]
- Example: Move Forward 50cm
- Makes robot go straight ahead
- Distance: 0-500 whole centimeters

Move Backward [distance]  
- Example: Move Backward 30cm
- Makes robot go in reverse
- Distance: 0-500 whole centimeters

Turn Left [angle]
- Example: Turn Left 90°
- Rotates robot counterclockwise
- Angle: 0-360 whole degrees

Turn Right [angle]
- Example: Turn Right 45°
- Rotates robot clockwise  
- Angle: 0-360 whole degrees
```

#### Control Blocks
```
Wait [time]
- Example: Wait 2000 ms (two seconds)
- Pauses program execution
- Time: 0-60000 whole milliseconds

Repeat [number] times
- Example: Repeat 4 times
- Executes contained blocks multiple times
- Number: 1-100 repetitions

If [condition]
- Example: If distance < 20cm
- Executes blocks only if condition is true
- Conditions: sensor comparisons

If [condition] Else
- Executes first blocks if true, second if false
- Useful for either/or decisions
```

#### Sensor Blocks
```
Distance Sensor
- Returns current obstacle distance
- Range: 2-400 centimeters
- Updates continuously

Battery Level
- Returns current battery percentage
- Range: 0-100%
- Useful for low-battery behaviors
```

### Appendix B: Error Messages and Solutions

**Common error messages you might see:**

```
"Robot not responding"
→ Check connection and battery level

"Obstacle detected - stopping"
→ Clear path or adjust program logic

"Invalid distance value"
→ Use whole numbers between 0-500 for movement

Low battery
→ Stop and recharge; an automatic low-battery movement lockout is not implemented

"Connection lost"
→ Move closer to robot, check Bluetooth
```

### Appendix C: Technical Specifications

**Historical capability targets (unverified for the selected P1 hardware):**
- Movement accuracy: ±2cm per meter
- Rotation accuracy: ±5 degrees
- Speed: the current 500 half-steps/s and assumed 65 mm wheel / 4096 half-steps per revolution imply approximately 2.5 cm/s before external gearing; measure the assembled robot
- Battery life: measurement pending with the selected 2200 mAh pack
- Sensor range: 2-400cm
- Operating temperature: 0-40°C
- Bluetooth range: 12+ meters line-of-sight

**Mobile App Requirements:**
- Android 7.0+ (API 24 minimum for the current build; iOS release support pending)
- Bluetooth 4.0+ (BLE support)
- 50MB storage space
- 2GB RAM recommended

### Appendix D: Warranty and Support

The following is historical packaged-product planning material. This DIY repository establishes no included battery/charger warranty or return service; use the selected component suppliers' actual terms.

**Limited Warranty:**
- Hardware: 1 year from purchase date
- Software: Free updates and bug fixes
- Battery: 6 months or 300 charge cycles
- Excludes damage from misuse or accidents

**What's Covered:**
- Manufacturing defects
- Component failures under normal use
- Software bugs and compatibility issues

**What's Not Covered:**
- Physical damage from drops or impacts
- Water damage
- Normal wear and tear
- Battery degradation after warranty period

**Warranty Claims:**
1. Contact support with serial number
2. Describe the problem in detail
3. Follow troubleshooting steps if requested
4. Return shipping instructions will be provided

---

**Need More Help?**

📧 **Email:** ayman.ouchker@outlook.com  
📱 **Community:** Join our Discord server for tips and project sharing

**Thank you for choosing our Educational Robot!**  
*Happy programming and learning! 🚀*

---

*User Manual Version 1.0 - Last Updated: June 2025*  
*© 2025 Educational Robot Project - Open Source MIT License*

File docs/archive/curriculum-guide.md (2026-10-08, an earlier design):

> **Historical planning material — archived 8 October 2026.** Use the [current curriculum guide](../curriculum-guide.md) for this build. This preserved version mixes proposed features, historical claims and implemented behavior; it is not an operating or release specification. Reported research figures remain subject to [reconciliation](../research-reconciliation.md), not revalidated by this archive.

# Educational Robot Curriculum Guide

## Overview

This comprehensive curriculum is designed to introduce children aged 7-12 to programming and computational thinking through hands-on robotics. The program follows a scaffolded approach, building from basic movement commands to complex autonomous behaviors over 20 structured lessons.

### Learning Philosophy

**Constructionist Learning:** Students learn by building and experimenting with tangible objects (the robot), making abstract programming concepts concrete and understandable.

**Progressive Complexity:** Each lesson builds upon previous knowledge, introducing new concepts gradually while reinforcing learned skills.

**Problem-Based Learning:** Students tackle real-world challenges that require creative problem-solving and critical thinking.

---

## Curriculum Structure

### 📚 Program Overview
- **Duration:** 20 lessons (10-20 weeks depending on frequency)
- **Age Range:** 7-12 years (adaptable for different grade levels)
- **Class Size:** 1-30 students (1 robot per 1-3 students recommended)
- **Prerequisites:** None - designed for complete beginners
- **Assessment:** Portfolio-based with peer collaboration emphasis

### 🎯 Learning Objectives

#### Computational Thinking Skills
- **Decomposition:** Breaking complex problems into manageable parts
- **Pattern Recognition:** Identifying similarities and patterns in problems
- **Abstraction:** Focusing on essential features while ignoring irrelevant details
- **Algorithm Design:** Creating step-by-step solutions to problems

#### Programming Concepts
- Sequential execution of commands
- Loops and repetition structures
- Conditional logic and decision making
- Sensor input and environmental awareness
- Debugging and iterative improvement

#### 21st Century Skills
- Problem-solving and critical thinking
- Creativity and innovation
- Communication and collaboration
- Digital literacy and technological fluency

---

## Lesson Plans

### Unit 1: Getting Started (Lessons 1-5)
*Age Focus: 7-9 years | Duration: 5 weeks*

#### Lesson 1: Meet Your Robot
**Duration:** 45 minutes  
**Learning Objectives:**
- Understand robot components and safety rules
- Successfully connect mobile device to robot
- Execute first simple movement command

**Materials Needed:**
- Educational robots (1 per 2-3 students)
- Tablets/smartphones with app installed
- Large open space for movement
- Safety cones or boundaries

**Lesson Structure:**

**Opening Circle (10 minutes)**
- Introduce robots as "programmable friends"
- Discuss what robots can and cannot do
- Review safety rules with demonstrations

**Exploration Time (20 minutes)**
- Students work in pairs to connect app to robot
- Guide students through connection process
- Celebrate successful connections with cheers!
- First command: make robot move forward 1 meter

**Reflection and Sharing (15 minutes)**
- What did you notice about how the robot moved?
- What questions do you have about robots?
- Preview next lesson: making shapes

**Assessment:**
- ✅ Can connect device to robot independently
- ✅ Successfully executes basic forward movement
- ✅ Follows safety rules during robot interaction

**Differentiation:**
- **Advanced students:** Try different distances and speeds
- **Struggling students:** Pair with tech-savvy partner
- **ELL students:** Use visual cards for robot vocabulary

---

#### Lesson 2: Making Shapes
**Duration:** 45 minutes  
**Learning Objectives:**
- Combine movement and turning commands
- Create geometric shapes through programming
- Understand sequencing in programming

**Lesson Structure:**

**Warm-up Review (5 minutes)**
- Quick robot connection check
- Review previous lesson's safety rules

**Guided Programming (25 minutes)**
- **Demo:** Teacher creates a square program on projector
- **Guided Practice:** Students follow along creating squares
- **Independent Work:** Students create triangles
- **Challenge:** Can you make a pentagon?

**Gallery Walk (15 minutes)**
- Students demonstrate their shape programs
- Peer feedback: "I liked how your robot..."
- Teacher documents successful programs with photos

**Assessment Rubric:**
- **Emerging (1):** Creates simple line movements
- **Developing (2):** Creates triangle or square with guidance
- **Proficient (3):** Creates multiple shapes independently
- **Advanced (4):** Creates complex shapes or patterns

---

#### Lesson 3: Robot Dance Party
**Duration:** 45 minutes  
**Learning Objectives:**
- Use timing blocks to create rhythmic patterns
- Express creativity through programming
- Understand the concept of program timing

**Materials:**
- Upbeat, child-friendly music
- Space for robot "dance floor"
- Optional: colored lights or decorations

**Lesson Structure:**

**Music and Movement (10 minutes)**
- Students dance to chosen song
- Identify different moves (spin, step, pause)
- Discuss how robots might "dance"

**Programming Dance Moves (25 minutes)**
- Introduce "Wait" blocks for timing
- Students program 3-4 move sequences
- Test dances with music playing
- Iterate and improve based on rhythm

**Dance Performance (10 minutes)**
- Each pair performs their robot dance
- Class votes on "Most Creative" and "Best Rhythm"
- Celebrate all performances with applause

**Extensions:**
- Program robot to dance to different genres
- Create group choreography with multiple robots
- Add LED patterns if robots have lights

---

#### Lesson 4: Obstacle Course Navigator
**Duration:** 45 minutes  
**Learning Objectives:**
- Introduce conditional logic (if/then)
- Use sensor input for decision making
- Develop problem-solving strategies

**Setup:**
- Simple obstacle course with boxes/books
- Clear paths between obstacles
- Multiple route options

**Lesson Structure:**

**Course Exploration (10 minutes)**
- Students walk through course manually
- Identify decision points: "If blocked, then turn"
- Discuss different possible routes

**Sensor Introduction (15 minutes)**
- Demonstrate distance sensor with hand
- Show how sensor readings change with obstacles
- Practice reading sensor values in app

**Programming Challenge (20 minutes)**
- Students program robots to navigate course
- Introduce "If distance < 20cm, then turn right"
- Test, debug, and refine programs
- Multiple attempts encouraged

**Assessment:**
- Document problem-solving approaches
- Note use of sensor-based decisions
- Observe collaboration and persistence

---

#### Lesson 5: Unit 1 Showcase
**Duration:** 60 minutes  
**Learning Objectives:**
- Demonstrate learning through presentations
- Reflect on programming journey so far
- Set goals for continued learning

**Showcase Format:**
- 5-minute presentations per pair/group
- Show favorite program and explain how it works
- Demonstrate one challenge they overcame
- Share what they want to learn next

**Assessment Portfolio:**
Students compile evidence of learning:
- Screenshots of programs created
- Photos of robots completing tasks
- Written reflection on favorite moment
- Goal setting for Unit 2

---

### Unit 2: Logic and Loops (Lessons 6-10)
*Age Focus: 8-10 years | Duration: 5 weeks*

#### Lesson 6: The Power of Repetition
**Duration:** 45 minutes  
**Learning Objectives:**
- Understand loop concepts and efficiency
- Use repeat blocks to simplify programs
- Recognize patterns that can be automated

**Opening Hook (10 minutes)**
- Challenge: Draw a 10-sided shape WITHOUT loops
- Students realize this would take forever!
- Introduce loops as "programming superpowers"

**Loop Exploration (25 minutes)**
- Convert square program to use repeat loop
- Compare original vs. loop version (fewer blocks!)
- Challenge: Create patterns using nested loops
- Experiment with different repetition counts

**Creative Challenge (10 minutes)**
- "Most interesting pattern" contest
- Students vote on creativity and technical skill
- Discuss how loops make complex patterns possible

**Mathematical Connections:**
- Count total movements in looped programs
- Predict robot's final position after loops
- Explore relationship between loop count and pattern size

---

#### Lesson 7: Smart Robot Decisions
**Duration:** 45 minutes  
**Learning Objectives:**
- Implement if/else conditional logic
- Create responsive robot behaviors
- Debug logical errors in programs

**Real-World Connection (10 minutes)**
- Discuss how students make decisions daily
- "If it's raining, then bring umbrella, else leave it home"
- Connect to how robots can make decisions too

**Programming Workshop (30 minutes)**
- **Basic If:** "If wall detected, then turn"
- **If/Else:** "If path clear, then go forward, else turn right"
- **Complex Conditions:** Multiple sensor checks
- Students test in various environments

**Debugging Practice (5 minutes)**
- Present broken programs for students to fix
- Common errors: wrong conditions, missing blocks
- Develop systematic debugging strategies

**Assessment Checklist:**
- ✅ Uses if statements correctly
- ✅ Implements if/else logic appropriately
- ✅ Can identify and fix logical errors
- ✅ Explains reasoning behind conditional choices

---

#### Lesson 8: Pattern Detectives
**Duration:** 45 minutes  
**Learning Objectives:**
- Identify patterns in robot behavior and environments
- Create programs that adapt to different situations
- Develop analytical thinking skills

**Pattern Hunt Activity (15 minutes)**
- Students observe various patterns (visual, musical, movement)
- Identify what repeats and what changes
- Discuss how patterns help predict future events

**Robot Pattern Programming (25 minutes)**
- Program robots to follow wall patterns
- Create patrol behaviors (back and forth)
- Implement spiral search patterns
- Challenge: Pattern that responds to obstacles

**Pattern Sharing Circle (5 minutes)**
- Students explain their pattern programs
- Others guess the pattern rule
- Discuss real-world applications

---

#### Lesson 9: Cooperative Robotics
**Duration:** 45 minutes (if multiple robots available)  
**Learning Objectives:**
- Plan coordinated multi-robot activities
- Understand timing and synchronization
- Practice communication and teamwork skills

**Coordination Challenges:**
- **Follow the Leader:** One robot leads, others follow
- **Formation Dancing:** Robots move in synchronized patterns
- **Relay Racing:** Sequential robot movements
- **Collaborative Art:** Robots draw parts of larger picture

**Alternative (Single Robot):**
- Students work in larger teams (4-5 members)
- Rotate roles: programmer, tester, documenter, presenter
- Create more complex individual robot behaviors
- Focus on human collaboration around robot programming

---

#### Lesson 10: Unit 2 Challenge Tournament
**Duration:** 60 minutes  
**Learning Objectives:**
- Apply all learned concepts in challenge setting
- Demonstrate problem-solving under time pressure
- Celebrate learning achievements

**Tournament Challenges:**
1. **Speed Challenge:** Navigate course fastest
2. **Efficiency Challenge:** Simplest program for complex task
3. **Creativity Challenge:** Most innovative use of loops/conditions
4. **Collaboration Challenge:** Team programming contest

**Reflection and Goal Setting:**
- What programming concepts feel comfortable now?
- What areas need more practice?
- What real-world problems could these skills solve?

---

### Unit 3: Sensors and Environment (Lessons 11-15)
*Age Focus: 9-11 years | Duration: 5 weeks*

#### Lesson 11: Robot Senses
**Duration:** 45 minutes  
**Learning Objectives:**
- Understand different types of sensors
- Use sensor data to make informed decisions
- Compare robot senses to human senses

**Sensory Exploration (15 minutes)**
- Students close eyes and navigate classroom
- Discuss how they used hearing, touch, smell
- Compare to robot's "eyes" (distance sensor) and "brain" (compass)

**Sensor Programming Workshop (25 minutes)**
- Advanced distance sensor applications
- Using compass/heading for navigation
- Battery monitoring for smart behavior
- Combining multiple sensor inputs

**Scientific Method Application (5 minutes)**
- Hypothesis: "Robot will detect obstacles at exactly 20cm"
- Test with various objects and distances
- Record actual vs. expected results
- Discuss sensor limitations and real-world factors

---

#### Lesson 12: Environmental Adaptation
**Duration:** 45 minutes  
**Learning Objectives:**
- Program robots to adapt to different environments
- Understand the concept of robust programming
- Test programs in multiple settings

**Environment Testing:**
- **Smooth Floor:** Optimal conditions
- **Carpet:** Different friction and speed
- **Bright/Dark Areas:** Light sensor variations (if available)
- **Narrow Spaces:** Precision movement requirements

**Adaptive Programming:**
- Programs that work in multiple environments
- Self-calibrating behaviors
- Error recovery strategies
- Graceful degradation when sensors fail

---

#### Lesson 13: Search and Rescue Mission
**Duration:** 60 minutes  
**Learning Objectives:**
- Apply programming skills to realistic scenario
- Use systematic search strategies
- Integrate multiple programming concepts

**Mission Briefing (10 minutes)**
- "Lost toy needs rescue in disaster zone"
- Robot must search area systematically
- Must avoid "dangerous" obstacles
- Find target and return to base

**Strategy Development (15 minutes)**
- Teams plan search patterns
- Consider efficiency vs. thoroughness
- Account for obstacles and dead ends
- Program backup plans for failures

**Mission Execution (30 minutes)**
- Teams program and test their rescue robots
- Multiple attempts allowed for improvement
- Document successful strategies
- Celebrate all rescue attempts

**Mission Debrief (5 minutes)**
- What worked well in your search strategy?
- What would you do differently next time?
- How do real search and rescue robots work?

---

#### Lesson 14: Robot Pet Simulator
**Duration:** 45 minutes  
**Learning Objectives:**
- Create complex, lifelike robot behaviors
- Understand state machines and behavior switching
- Express creativity through robot personality

**Pet Behavior Design (15 minutes)**
- Students design robot "pet" personalities
- Happy, curious, sleepy, playful, cautious
- Identify trigger conditions for behavior changes
- Plan interaction responses

**Programming Workshop (25 minutes)**
- **Wandering Behavior:** Random exploration
- **Attention Seeking:** Approach people/movement
- **Rest Mode:** Low activity when battery drops
- **Play Mode:** Energetic movements and patterns

**Pet Show and Tell (5 minutes)**
- Students present their robot pets
- Demonstrate different personality modes
- Vote on "Most Realistic Pet Behavior"

---

#### Lesson 15: Unit 3 Innovation Fair
**Duration:** 60 minutes  
**Learning Objectives:**
- Synthesize learning into original projects
- Present technical work to authentic audience
- Reflect on growth as programmers

**Innovation Fair Projects:**
Students choose from:
- **Environmental Monitor:** Robot that patrols and reports conditions
- **Assistant Robot:** Helps with specific tasks or routines
- **Entertainment Robot:** Interactive games or performances
- **Explorer Robot:** Mapping and discovery behaviors

**Presentation Format:**
- 3-minute demonstration
- Explain problem solved and approach taken
- Show most challenging part and how overcome
- Answer questions from visitors

---

### Unit 4: Advanced Autonomy (Lessons 16-20)
*Age Focus: 10-12 years | Duration: 5 weeks*

#### Lesson 16: Artificial Intelligence Basics
**Duration:** 45 minutes  
**Learning Objectives:**
- Understand basic AI concepts through robotics
- Implement simple learning behaviors
- Discuss AI ethics and implications

**AI Demystification (15 minutes)**
- What is "intelligence" in humans vs. robots?
- Simple AI: following rules vs. complex AI: learning
- Examples of AI in daily life (recommendations, maps, games)

**Simple Learning Implementation (25 minutes)**
- Robot "remembers" obstacle locations
- Adapts behavior based on success/failure
- Improves performance over multiple runs
- Basic path optimization

**Ethics Discussion (5 minutes)**
- When should robots make decisions vs. humans?
- How do we ensure robot behaviors are safe and fair?
- Future careers in AI and robotics

---

#### Lesson 17: Swarm Intelligence
**Duration:** 45 minutes (multiple robots needed)  
**Learning Objectives:**
- Understand emergence in complex systems
- Program coordinated group behaviors
- Explore collective problem-solving

**Swarm Behaviors:**
- **Flocking:** Robots move together like birds
- **Foraging:** Collective resource gathering
- **Construction:** Building patterns together
- **Communication:** Information sharing between robots

**Alternative for Single Robot:**
- Simulate swarm with virtual robots on screen
- Program complex individual behaviors
- Study real swarm examples (ants, bees, fish)
- Design swarm algorithms on paper

---

#### Lesson 18: Real-World Robotics
**Duration:** 45 minutes  
**Learning Objectives:**
- Connect classroom learning to real applications
- Explore robotics careers and pathways
- Design solutions to authentic problems

**Career Exploration:**
- **Medical Robots:** Surgery, rehabilitation, assistance
- **Space Robots:** Mars rovers, space station arms
- **Industrial Robots:** Manufacturing, assembly, inspection
- **Service Robots:** Cleaning, delivery, security

**Problem-Solving Challenge:**
Students choose real-world problem and design robot solution:
- Cleaning up ocean plastic
- Assisting elderly or disabled individuals
- Exploring dangerous environments
- Agricultural automation

**Presentation Format:**
- Problem statement and why it matters
- Robot design and capabilities needed
- Programming approach and key challenges
- Potential impact and implementation plan

---

#### Lesson 19: Student Choice Projects
**Duration:** 60 minutes  
**Learning Objectives:**
- Demonstrate mastery through self-directed projects
- Integrate all learned programming concepts
- Show creativity and personal interest

**Project Categories:**
- **Technical Challenge:** Push programming limits
- **Artistic Expression:** Creative robot behaviors
- **Social Good:** Robot that helps others
- **Scientific Investigation:** Test hypothesis with robot

**Project Requirements:**
- Use at least 3 different programming concepts
- Include documentation of design process
- Demonstrate working solution
- Reflect on learning and challenges overcome

---

#### Lesson 20: Culminating Exhibition
**Duration:** 90 minutes  
**Learning Objectives:**
- Celebrate learning journey and achievements
- Share knowledge with broader community
- Reflect on growth and future goals

**Exhibition Format:**
- **Student Presentations:** 5 minutes each
- **Interactive Demos:** Visitors try programming
- **Portfolio Displays:** Document learning journey
- **Peer Teaching:** Students teach younger children
- **Future Visioning:** Where will robotics go next?

**Assessment Portfolio Final Elements:**
- Complete program collection (screenshots)
- Video demonstrations of key projects
- Written reflection on learning journey
- Peer feedback and collaboration evidence
- Goal setting for continued learning

---

## Assessment Framework

### 🎯 Formative Assessment Strategies

#### Daily Observation Checklist
- [ ] Engages actively with programming challenges
- [ ] Shows persistence when programs don't work initially
- [ ] Collaborates effectively with partners
- [ ] Asks thoughtful questions about robot behavior
- [ ] Makes connections between programming and real world

#### Weekly Reflection Prompts
1. **What did I learn this week about programming?**
2. **What was most challenging and how did I work through it?**
3. **How did I help a classmate or get help when needed?**
4. **What would I like to explore next with the robot?**

#### Peer Assessment Activities
- **Program Gallery Walk:** Students view and comment on each other's work
- **Debugging Partners:** Help each other find and fix program errors
- **Teaching Moments:** Advanced students mentor those still learning
- **Collaboration Feedback:** Reflect on teamwork and communication skills

### 📊 Summative Assessment Options

#### Portfolio-Based Assessment
**Contents:**
- Collection of programs created throughout course
- Photos/videos of robots completing challenges
- Written reflections on learning process
- Documentation of collaboration and peer teaching
- Evidence of growth and skill development

**Scoring Rubric:**
- **Novice (1):** Basic understanding, needs significant support
- **Developing (2):** Growing understanding, some independent work
- **Proficient (3):** Strong understanding, works independently
- **Advanced (4):** Deep understanding, helps others learn

#### Performance Tasks
**Example: Robot Problem-Solving Challenge**
- Present students with novel obstacle course
- 30 minutes to program solution
- Assess problem-solving process, not just success
- Allow multiple attempts and revisions

#### Traditional Assessment Adaptations
**Programming Concept Check:**
- Visual quiz with block diagrams
- "Predict the behavior" scenarios
- Error identification and correction
- Concept application to new situations

### 🎓 Differentiation Strategies

#### For Advanced Learners
- **Extension Challenges:** More complex programming problems
- **Mentoring Roles:** Help teach struggling classmates
- **Independent Projects:** Self-directed exploration opportunities
- **Real-World Connections:** Research actual robotics applications

#### For Struggling Learners
- **Peer Support:** Pair with patient, skilled partners
- **Simplified Challenges:** Break complex tasks into smaller steps
- **Visual Supports:** More diagrams and demonstrations
- **Multiple Modalities:** Kinesthetic learning through physical movement

#### For English Language Learners
- **Visual Programming:** Blocks reduce language barriers
- **Peer Translation:** Native speakers explain concepts
- **Technical Vocabulary:** Explicit instruction in key terms
- **Cultural Connections:** Relate robots to students' backgrounds

#### For Students with Disabilities
- **Assistive Technology:** Voice control or switch access if needed
- **Collaborative Programming:** Share roles based on abilities
- **Sensory Considerations:** Adjust for visual, auditory, or motor needs
- **Individual Accommodations:** Work with special education team

---

## Implementation Guidelines

### 🏫 Classroom Setup and Management

#### Physical Space Requirements
- **Open Area:** Minimum 3×3 meters for robot movement
- **Flexible Seating:** Allow students to move between programming and testing
- **Charging Station:** Central location for robot battery management
- **Storage Solutions:** Secure storage for robots and devices
- **Safety Boundaries:** Clear areas where robots should not go

#### Technology Management
- **Device Policies:** Clear rules for handling robots and tablets/phones
- **Troubleshooting Protocols:** Student tech helpers and escalation procedures
- **Backup Plans:** Activities for when technology fails
- **Digital Citizenship:** Responsible use of programming tools

#### Classroom Culture
- **Growth Mindset:** Emphasize learning from failures and iterations
- **Collaboration Norms:** Explicit teaching of teamwork skills
- **Celebration Rituals:** Regular recognition of progress and achievement
- **Risk-Taking Support:** Encourage experimentation and creative thinking

### 👨‍🏫 Teacher Preparation and Support

#### Professional Development Needs
- **Programming Fundamentals:** Basic understanding of concepts being taught
- **Robot Operation:** Hands-on experience with hardware and software
- **Troubleshooting Skills:** Common problems and solutions
- **Pedagogical Approaches:** Best practices for teaching computational thinking

#### Ongoing Support Resources
- **Online Community:** Teacher forums and resource sharing
- **Video Tutorials:** Step-by-step guides for lesson implementation
- **Technical Support:** Direct assistance with hardware/software issues
- **Curriculum Updates:** Regular improvements based on classroom feedback

#### Pre-Implementation Checklist
- [ ] Teacher completes robot programming tutorial
- [ ] Classroom space prepared and tested
- [ ] All robots charged and functional
- [ ] Student devices have app installed and tested
- [ ] Safety procedures reviewed and posted
- [ ] Parent/guardian information sent home
- [ ] Assessment rubrics prepared and understood

### 📅 Flexible Scheduling Options

#### Intensive Format (Daily for 4 weeks)
- **Best for:** Summer camps, intensive programs
- **Schedule:** 90 minutes daily
- **Benefits:** Rapid skill building, sustained engagement
- **Considerations:** May be overwhelming for younger students

#### Standard Format (2-3 times per week for 10 weeks)
- **Best for:** Regular classroom integration
- **Schedule:** 45-60 minutes per session
- **Benefits:** Time for reflection and skill consolidation
- **Considerations:** Requires consistent access to robots

#### Extended Format (Weekly for 20 weeks)
- **Best for:** After-school programs, clubs
- **Schedule:** 60-90 minutes weekly
- **Benefits:** Deep exploration of concepts
- **Considerations:** Need strong session connections

#### Integrated Format (Cross-curricular throughout year)
- **Best for:** Schools with limited technology time
- **Schedule:** Flexible integration into math, science, language arts
- **Benefits:** Reinforces multiple subject areas
- **Considerations:** Requires careful curriculum mapping

---

## Cross-Curricular Connections

### 🔢 Mathematics Integration

#### Geometry and Spatial Reasoning
**Grade 2-3 Connections:**
- **Shapes and Angles:** Program robots to trace geometric shapes
- **Measurement:** Use robot movements to explore distance and perimeter
- **Symmetry:** Create symmetrical robot path patterns

**Grade 4-5 Connections:**
- **Coordinate Grids:** Navigate robots using coordinate instructions
- **Angles:** Precise turning using degree measurements
- **Area and Perimeter:** Calculate space covered by robot paths

**Sample Math-Robot Lesson:**
```
Topic: Understanding Perimeter (Grade 3)
1. Review perimeter definition with manipulatives
2. Program robot to trace rectangle with specific dimensions
3. Measure actual robot path vs. programmed path
4. Calculate perimeter and discuss measurement precision
5. Challenge: Create shape with exact perimeter of 200cm
```

#### Data and Probability
- **Data Collection:** Gather sensor readings over time
- **Graphing:** Chart robot performance metrics
- **Probability:** Predict random robot behaviors
- **Statistics:** Analyze success rates across multiple trials

### 🔬 Science Integration

#### Physics Concepts
**Forces and Motion:**
- Explore acceleration and deceleration through robot speed
- Investigate friction effects on different surfaces
- Study momentum through collision simulations
- Understand energy transfer from battery to movement

**Waves and Sound:**
- Ultrasonic sensor technology and sound waves
- Programming robot responses to sound inputs
- Creating sound patterns through robot movements
- Exploring frequency and wavelength concepts

**Sample Science-Robot Investigation:**
```
Question: How does surface texture affect robot speed?
Hypothesis: Rougher surfaces will slow the robot down
Variables: Surface type (independent), speed (dependent)
Method: Program identical paths on carpet, wood, tile
Data: Time measurements for each surface
Conclusion: Analyze results and explain using friction concepts
```

#### Engineering Design Process
1. **Ask:** What problem needs solving?
2. **Imagine:** Brainstorm robot-based solutions
3. **Plan:** Design robot behavior and programming approach
4. **Create:** Build and program robot solution
5. **Test:** Evaluate performance against criteria
6. **Improve:** Iterate based on testing results

### 📚 Language Arts Integration

#### Technical Writing
- **Instruction Manuals:** Write clear robot operation guides
- **Process Documentation:** Describe programming steps for others
- **Troubleshooting Guides:** Create help documents for common problems
- **Reflection Journals:** Document learning journey and insights

#### Creative Writing
- **Robot Stories:** Create narratives featuring robot characters
- **Science Fiction:** Imagine future robot capabilities and implications
- **Poetry:** Write poems about robot movements and behaviors
- **Dialogue:** Script conversations between humans and robots

**Sample Language Arts Activity:**
```
"Robot Adventure Story" (Grades 3-5)
1. Students program robot to navigate obstacle course
2. Create story explaining robot's "mission" and challenges
3. Write dialogue between robot and obstacles it encounters
4. Present story while demonstrating robot program
5. Peer feedback on both technical and creative elements
```

#### Vocabulary Development
**Technical Terms:**
- Algorithm, sequence, loop, condition, sensor, autonomous
- Debug, iterate, program, code, input, output
- Coordinate, angle, distance, direction, navigation

**Academic Language:**
- Hypothesis, predict, analyze, conclude, evaluate
- Compare, contrast, classify, synthesize, communicate
- Collaborate, reflect, revise, justify, explain

### 🌍 Social Studies Integration

#### Geography and Mapping
- **Cardinal Directions:** Navigate robots using compass directions
- **Scale and Distance:** Program journeys between "cities" 
- **Topographic Understanding:** Navigate elevation changes
- **Cultural Exploration:** Program robots to "visit" world landmarks

#### History and Technology
- **Timeline Creation:** Evolution of robotics and automation
- **Historical Problem-Solving:** How might robots have helped in past eras?
- **Cultural Impact:** Discuss how robotics changes society
- **Future Prediction:** Imagine robotics in students' adult lives

#### Economics and Ethics
- **Cost-Benefit Analysis:** Compare robot solutions to human labor
- **Resource Management:** Efficient robot path planning
- **Ethical Decision Making:** When should robots make choices?
- **Global Impact:** How robotics affects different communities

---

## Research and Evaluation

### 📊 Learning Outcomes Data

#### Quantitative Measures
**Based on pilot implementation with 150 students ages 7-12:**

**Computational Thinking Assessment (Pre/Post)**
- Decomposition skills: 78% improvement
- Pattern recognition: 82% improvement  
- Abstraction abilities: 71% improvement
- Algorithm design: 85% improvement

**Programming Concept Mastery**
- Sequencing: 95% of students demonstrate proficiency
- Loops: 87% achieve proficiency by Unit 2 end
- Conditionals: 79% master basic if/then logic
- Sensor integration: 73% successfully use sensor data

**Engagement Metrics**
- Average session engagement: 43 minutes
- Voluntary continuation rate: 89%
- Parent reports of home discussion: 92%
- Student requests for additional sessions: 78%

#### Qualitative Findings

**Student Voice Feedback:**
"I never knew programming could be so fun! Now I want to learn how to make video games too." - Age 9

"The robot helped me understand math better because I could see how the angles worked when it turned." - Age 11

"I love that when my program didn't work, I could just try again until I figured it out." - Age 8

**Teacher Observations:**
- Increased persistence when facing challenges
- Enhanced collaboration and peer teaching
- Greater confidence in problem-solving approaches
- Improved mathematical reasoning and spatial thinking

**Parent Feedback:**
- 94% report increased interest in STEM subjects
- 87% observe improved logical thinking at home
- 91% would recommend program to other families
- 83% report children teaching family members about programming

### 🎯 Research-Based Best Practices

#### Effective Pedagogy for Robotics Education

**Constructionist Approach Validation:**
- Hands-on manipulation significantly improves concept retention
- Physical robot feedback makes abstract concepts concrete
- Student-driven exploration leads to deeper understanding
- Tangible results increase motivation and engagement

**Collaborative Learning Benefits:**
- Peer programming reduces individual frustration
- Diverse perspectives improve problem-solving quality
- Teaching others reinforces personal understanding
- Social interaction sustains long-term interest

**Progressive Complexity Effectiveness:**
- Scaffolded challenges maintain optimal difficulty
- Success at each level builds confidence for next challenges
- Clear learning progressions help students track growth
- Multiple entry points accommodate diverse skill levels

#### Assessment Innovation

**Portfolio-Based Assessment Advantages:**
- Captures learning process, not just final products
- Allows for multiple forms of evidence
- Students take ownership of learning documentation
- Teachers gain insights into student thinking

**Performance Task Validity:**
- Real-world challenges test transfer of learning
- Multiple solution paths demonstrate creativity
- Time constraints mirror authentic problem-solving
- Revision opportunities reflect iterative design process

**Peer Assessment Benefits:**
- Students develop evaluation and feedback skills
- Multiple perspectives improve solution quality
- Collaborative assessment builds community
- Self-reflection skills transfer to other subjects

### 📈 Longitudinal Impact Studies — pending source verification

> The following historical claims conflict with the research document's statement that no extended follow-up was conducted. They are preserved for reconciliation, not approved for use as established outcomes. Verify follow-up dates, participants and analysis against original records before including these claims in a final submission. See [research reconciliation](../research-reconciliation.md).

#### 6-Month Follow-Up Results
**Academic Performance Correlations:**
- 23% improvement in mathematics problem-solving scores
- 18% increase in science inquiry skills demonstrations
- 31% improvement in technology literacy assessments
- 15% growth in creative thinking evaluations

**Attitude and Interest Changes:**
- 67% express interest in programming-related courses
- 54% report increased confidence in technology use
- 78% demonstrate improved persistence with challenging tasks
- 41% show interest in engineering or computer science careers

#### 12-Month Extended Impact
**Sustained Learning:**
- 89% of students retain basic programming concepts
- 72% can successfully debug simple programs
- 84% explain robot behavior using correct terminology
- 91% express continued interest in robotics

**Transfer to Other Domains:**
- Improved logical reasoning in mathematics
- Enhanced scientific hypothesis formation
- Better structured approach to complex projects
- Increased comfort with technology integration

### 🔬 Research Validation Framework

#### Empirical Evidence Collection
**Quantitative Measures:**
- Pre/post computational thinking assessments
- Standardized problem-solving evaluations
- Technology literacy skill demonstrations
- Academic achievement correlation analysis

**Qualitative Documentation:**
- Student interview protocols
- Teacher observation rubrics
- Parent questionnaire responses
- Long-term impact case studies

#### Experimental Design Considerations
**Control Group Comparisons:**
- Students using traditional programming interfaces
- Classes without robotics integration
- Different pedagogical approaches (direct instruction vs. inquiry)
- Varying implementation intensity levels

**Variable Analysis:**
- Age-related effectiveness differences
- Gender participation and achievement patterns
- Socioeconomic impact factors
- Prior technology experience influences

#### Validity and Reliability Measures
**Internal Validity:**
- Consistent assessment protocols across sites
- Standardized implementation guidelines
- Regular inter-rater reliability checks
- Triangulated data collection methods

**External Validity:**
- Multiple geographic implementation sites
- Diverse demographic participant populations
- Various educational setting types
- Cross-cultural adaptation studies

---

## Professional Development Framework

### 👨‍🏫 Teacher Preparation Program

#### Core Competency Development
**Technical Skills (20 hours)**
- Robot operation and basic troubleshooting
- Mobile app functionality and features
- Programming concept foundations
- Safety protocols and classroom management

**Pedagogical Knowledge (15 hours)**
- Constructionist learning principles
- Computational thinking instruction strategies
- Assessment techniques for hands-on learning
- Differentiation approaches for diverse learners

**Implementation Planning (10 hours)**
- Curriculum mapping and pacing guides
- Classroom setup and resource management
- Parent and administrator communication
- Sustainability and program growth planning

#### Professional Learning Community
**Monthly Meetings:**
- Share successful lesson implementations
- Collaborative problem-solving for challenges
- Resource development and sharing
- Guest expert presentations

**Online Collaboration:**
- Digital resource library access
- Discussion forums for ongoing support
- Lesson plan template sharing
- Student work showcase platform

**Annual Conference:**
- Advanced training workshops
- Research findings presentations
- Vendor exhibitions and updates
- Networking and partnership building

### 📋 Implementation Support Tools

#### Lesson Planning Resources
**Template Structure:**
- Learning objectives aligned to standards
- Material lists and setup requirements
- Step-by-step implementation guides
- Assessment rubrics and checklists
- Extension activities for diverse learners

**Customization Options:**
- Grade-level adaptations
- Time allocation flexibility
- Resource substitution suggestions
- Cultural responsiveness modifications

#### Assessment Tools
**Formative Assessment Bank:**
- Daily observation checklists
- Student self-reflection prompts
- Peer feedback protocols
- Quick concept check activities

**Summative Assessment Options:**
- Portfolio compilation guidelines
- Performance task rubrics
- Traditional assessment adaptations
- Parent communication templates

#### Troubleshooting Guides
**Technical Issues:**
- Common connectivity problems and solutions
- Robot maintenance and care procedures
- App troubleshooting decision trees
- Emergency backup activity plans

**Pedagogical Challenges:**
- Student engagement strategies
- Differentiation implementation guides
- Classroom management techniques
- Assessment interpretation support

---

## Future Enhancements and Research

### 🚀 Technology Evolution Roadmap

#### Hardware Improvements (6-12 months)
- **Enhanced Sensors:** Camera modules for computer vision
- **Expanded Connectivity:** Robot-to-robot communication
- **Modular Design:** Interchangeable sensor and actuator modules
- **Improved Battery:** Longer life and faster charging capabilities

#### Software Developments (3-6 months)
- **iOS Application:** Full feature parity with Android version
- **Cloud Integration:** Program sharing and collaboration features
- **AI Integration:** Machine learning blocks for advanced users
- **Multilingual Support:** Expanded language options

#### Curriculum Extensions (12-18 months)
- **Advanced Robotics:** Integration with external sensors and actuators
- **Internet of Things:** Connected device programming
- **Artificial Intelligence:** Basic machine learning concepts
- **Environmental Science:** Data collection and analysis projects

### 🔬 Ongoing Research Questions

#### Learning Effectiveness Studies
- **Optimal Group Size:** Individual vs. pair vs. small group programming
- **Session Frequency:** Daily vs. weekly vs. intensive format effectiveness
- **Long-term Retention:** Multi-year impact on STEM interest and achievement
- **Transfer Effects:** Application to other programming environments

#### Pedagogical Innovation Research
- **Teacher Professional Development:** Most effective training approaches
- **Assessment Innovation:** Alternative evaluation methods development
- **Differentiation Strategies:** Supporting diverse learning needs
- **Integration Models:** Cross-curricular implementation effectiveness

#### Technology Impact Analysis
- **Digital Divide Mitigation:** Effectiveness in low-resource settings
- **Accessibility Enhancement:** Support for students with disabilities
- **Cultural Adaptation:** Implementation across diverse cultural contexts
- **Sustainability Factors:** Long-term program viability elements

### 🌟 Vision for Expansion

#### Geographic Scaling
**Regional Implementation:**
- Pilot programs in 10 additional school districts
- Rural and urban context comparison studies
- International adaptation for different educational systems
- Community organization partnerships

**Global Reach:**
- Open-source curriculum translation projects
- International educator exchange programs
- Cross-cultural robotics collaboration projects
- Global student robotics competition development

#### Institutional Partnerships
**Higher Education Collaboration:**
- University research partnerships
- Teacher preparation program integration
- Student teacher placement opportunities
- Graduate research project coordination

**Industry Connections:**
- Technology company mentorship programs
- Real-world problem challenge development
- Career exploration and pathway development
- Equipment donation and sustainability programs

#### Community Impact
**Family Engagement:**
- Home robotics learning kits
- Parent-child programming workshops
- Community maker space partnerships
- Intergenerational learning programs

**Societal Applications:**
- Robotics therapy for special populations
- Senior citizen technology literacy programs
- Community problem-solving robotics challenges
- Public awareness and advocacy campaigns

---

## Appendices

### Appendix A: Standards Alignment

#### Computer Science Standards (K-12 Framework)
**Grades K-2:**
- 1A-AP-10: Develop programs with sequences and simple loops
- 1A-AP-13: Give attribution when using ideas of others
- 1A-AP-14: Debug programs through observation and testing

**Grades 3-5:**
- 1B-AP-08: Compare and refine multiple algorithms for the same task
- 1B-AP-10: Create programs incorporating learned concepts
- 1B-AP-13: Use an iterative process to plan development of a program

#### Mathematics Standards (Common Core)
**Grade 2:**
- 2.MD.A.1: Measure and estimate lengths using standard units
- 2.G.A.1: Recognize and draw shapes with specified attributes

**Grade 3:**
- 3.MD.C.7: Relate area to multiplication and addition
- 3.G.A.1: Understand shared attributes of categories of shapes

**Grade 4:**
- 4.MD.C.7: Recognize angle measure as additive
- 4.G.A.1: Draw points, lines, line segments, rays, angles

**Grade 5:**
- 5.G.A.1: Use coordinate systems to represent and solve problems
- 5.G.A.2: Represent real-world and mathematical problems by graphing

#### Science Standards (Next Generation)
**Engineering Design (K-5):**
- K-2-ETS1-1: Ask questions, make observations, gather information
- 3-5-ETS1-1: Define criteria and constraints of design problem
- 3-5-ETS1-2: Generate and compare multiple possible solutions
- 3-5-ETS1-3: Plan and carry out fair tests to identify aspects of a model

### Appendix B: Resource Lists

#### Required Materials
**Per 2-3 Students:**
- 1 Educational robot (assembled)
- 1 Smartphone or tablet (Android 5.0+)
- 1 Charging cable and power adapter
- Access to open space (3×3 meters minimum)

**Classroom Supplies:**
- Masking tape for marking boundaries
- Cardboard boxes for obstacles
- Measuring tools (rulers, meter sticks)
- Chart paper for documentation
- Markers and colored pencils

#### Optional Enhancements
- Colored LED strips for robot decoration
- Small objects for search and rescue activities
- Different surface materials for testing
- Sound equipment for robot dance activities
- Video recording equipment for documentation

#### Digital Resources
- Lesson plan templates (downloadable)
- Assessment rubrics (customizable)
- Video tutorials (streaming access)
- Community forum (registration required)
- Technical support portal (account-based)

### Appendix C: Safety Protocols

#### General Safety Guidelines
- Adult supervision required for ages 7-9
- Clear boundaries for robot operation areas
- Regular equipment inspection and maintenance
- Emergency stop procedures clearly posted
- First aid kit accessible during activities

#### Specific Risk Mitigation
**Collision Prevention:**
- Programming limits on robot speed
- Automatic obstacle detection and stopping
- Clear visual boundaries for operation areas
- Student training on safe robot handling

**Electrical Safety:**
- Proper charging procedures and supervision
- Battery inspection for damage or swelling
- Cord management to prevent tripping hazards
- Adult-only access to internal electronics

**Age-Appropriate Guidelines:**
- Ages 7-8: Constant adult supervision
- Ages 9-10: Adult nearby, periodic check-ins
- Ages 11-12: Independent operation with clear rules
- All ages: Stop immediately if problems occur

---

**Curriculum Guide Version 1.0**  
*© 2025 Educational Robot Project - Open Source MIT License*  
*For updates and additional resources: educational-robot.com/curriculum*

*This curriculum has been developed through extensive classroom testing and research validation. We encourage adaptation and improvement for your specific educational context.*

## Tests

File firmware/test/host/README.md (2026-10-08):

# Host regression doubles

`run_tests.py` compiles `harness.cpp`, which includes the production firmware sources directly. The stubs emulate the Arduino, BLE and FreeRTOS APIs needed by those sources. Motor GPIO writes and BLE notification fragments are recorded, and delay hooks reproduce STOP arriving during a blocking movement. Real mutexes protect the emulated critical sections.

JSON serialization is a small test double; the PlatformIO build checks integration with the pinned ArduinoJson library. These tests establish software behavior, not physical safety or over-the-air delivery. Run a full firmware build and the hardware acceptance checks in `../../README.md` as well.

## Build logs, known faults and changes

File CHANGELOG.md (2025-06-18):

# Changelog

All notable changes to this project will be documented in this file.

## [1.0.0] - 2025-06-18

### Added
- Initial release of educational robot platform
- ESP32-based firmware with BLE communication
- Flutter mobile app with visual programming
- Progressive learning system (4 levels)
- Autonomous navigation using E-Bug algorithm
- Real-time telemetry and sensor feedback
- Complete hardware designs and assembly guide
- Educational curriculum and lesson plans

### Features
- Sub-$40 total cost
- ±2cm movement accuracy
- 90+ minute battery life
- Mobile-first design approach
- Offline capability

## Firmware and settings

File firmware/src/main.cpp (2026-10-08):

/**
 * E-Bug Educational Robot - Main Program
 * 
 * An affordable educational robotics platform for teaching programming
 * concepts to children aged 7-12 through hands-on interaction.
 * 
 * Features:
 * - ESP32-based hardware with stepper motors
 * - BLE communication with mobile app
 * - Progressive learning system
 * - Autonomous navigation with E-Bug algorithm
 * - Real-time sensor telemetry
 * 
 * Author: Mohamed Ayman OUCHKER
 * Institution: Euromed University of Fes
 * Project: End of Studies Project 2024-2025
 */

#include <Arduino.h>
#include <freertos/FreeRTOS.h>
#include <freertos/task.h>

// Project modules
#include "config.h"
#include "types.h"
#include "motor_control.h"
#include "sensor_manager.h"
#include "ble_communication.h"
#include "navigation.h"

// Task handles
TaskHandle_t motorTaskHandle = NULL;
TaskHandle_t sensorTaskHandle = NULL;
TaskHandle_t communicationTaskHandle = NULL;

// Global state
RobotState currentState = IDLE;
unsigned long lastHeartbeat = 0;
bool systemInitialized = false;

// Function prototypes
void motorTask(void *parameter);
void sensorTask(void *parameter);
void communicationTask(void *parameter);
void executeCommand(const Command& cmd);
void printSystemStatus();
void handleSystemError(const String& error);
bool initializeSystem();

void setup() {
  Serial.begin(115200);
  delay(1000); // Wait for serial monitor
  
  Serial.println("========================================");
  Serial.println("E-Bug Educational Robot Starting...");
  Serial.println("Version: 1.0.0");
  Serial.println("========================================");
  
  // Initialize all subsystems
  if (!initializeSystem()) {
    Serial.println("FATAL: System initialization failed!");
    handleSystemError("System initialization failed");
    return;
  }
  
  // Create FreeRTOS tasks
  Serial.println("Creating system tasks...");
  
  // Motor control task (Core 1 - for real-time control)
  xTaskCreatePinnedToCore(
    motorTask,                    // Task function
    "MotorTask",                 // Task name
    MOTOR_TASK_STACK,            // Stack size
    NULL,                        // Parameters
    2,                           // Priority (high)
    &motorTaskHandle,            // Task handle
    1                            // Core 1
  );
  
  // Sensor management task (Core 0)
  xTaskCreatePinnedToCore(
    sensorTask,                  // Task function
    "SensorTask",               // Task name
    SENSOR_TASK_STACK,          // Stack size
    NULL,                       // Parameters
    1,                          // Priority (medium)
    &sensorTaskHandle,          // Task handle
    0                           // Core 0
  );
  
  // Communication task (Core 0)
  xTaskCreatePinnedToCore(
    communicationTask,           // Task function
    "CommTask",                 // Task name
    COMM_TASK_STACK,            // Stack size
    NULL,                       // Parameters
    1,                          // Priority (medium)
    &communicationTaskHandle,   // Task handle
    0                           // Core 0
  );
  
  systemInitialized = true;
  Serial.println("System initialization complete!");
  Serial.println("Robot ready for commands...");
  
  // Initial system status
  printSystemStatus();
}

void loop() {
  // Main loop handles connection management and heartbeat
  if (systemInitialized) {
    // Handle BLE connection state
    bleManager.handleConnection();
    
    // Heartbeat every 10 seconds
    if (millis() - lastHeartbeat > 10000) {
      lastHeartbeat = millis();
      Serial.printf("Heartbeat - Uptime: %lu ms, Free heap: %d bytes\n", 
                    millis(), ESP.getFreeHeap());
      
      if (bleManager.isConnected()) {
        bleManager.sendStatus("heartbeat");
      }
    }
  }
  
  delay(100); // Prevent watchdog reset
}

bool initializeSystem() {
  Serial.println("Initializing subsystems...");
  
  // Initialize motor control
  Serial.print("- Motor control... ");
  motorController.begin();
  Serial.println("OK");
  
  // Initialize sensor management
  Serial.print("- Sensor management... ");
  sensorManager.begin();
  if (!sensorManager.testAllSensors()) {
    Serial.println("WARNING: Some sensors failed tests");
  } else {
    Serial.println("OK");
  }
  
  // Initialize BLE communication
  Serial.print("- BLE communication... ");
  bleManager.begin();
  Serial.println("OK");
  
  // Initialize navigation
  Serial.print("- Navigation system... ");
  navigator.begin();
  Serial.println("OK");
  
  Serial.println("All subsystems initialized successfully");
  return true;
}

void motorTask(void *parameter) {
  Serial.println("Motor task started on Core 1");
  
  while (true) {
    // Process commands from BLE
    if (bleManager.hasCommand()) {
      Command cmd = bleManager.getNextCommand();
      executeCommand(cmd);
    }
    
    // Handle autonomous navigation
    if (navigator.isAutonomous()) {
      navigator.executeAutonomousStep();
    }
    
    // Task delay
    vTaskDelay(pdMS_TO_TICKS(MOTOR_TASK_DELAY));
  }
}

void sensorTask(void *parameter) {
  unsigned long lastRange = 0;
  while (true) {
    sensorManager.updateIMU();
    if (millis() - lastRange >= SENSOR_UPDATE_RATE) {
      lastRange = millis();
      sensorManager.updateSensorData();
    }
    vTaskDelay(pdMS_TO_TICKS(IMU_UPDATE_RATE));
  }
}

void communicationTask(void *parameter) {
  while (true) {
    // Notification transmission never delays the safety sensor sampling task.
    if (bleManager.isConnected()) bleManager.sendTelemetry(sensorManager.getSensorData());
    vTaskDelay(pdMS_TO_TICKS(TELEMETRY_UPDATE_RATE));
  }
}

void executeCommand(const Command& cmd) {
  if (cmd.type == '?') return; // empty queue is not a STOP command
  if (cmd.generation != motorController.getGeneration()) {
    bleManager.sendCommandResult(cmd.id, "cancelled", "superseded by stop");
    return;
  }
  if (cmd.type == 'K' && cmd.value == 0) {
    bleManager.sendCommandResult(cmd.id, "done"); // open-loop is always used in P1
    return;
  }
  const bool movement = cmd.type == 'F' || cmd.type == 'B' || cmd.type == 'L' || cmd.type == 'R';
  if (!movement && !(cmd.type == 'A' && cmd.value == 1)) {
    bleManager.sendCommandResult(cmd.id, "error", "unsupported queued command");
    return;
  }
  // The generation check and rearming are atomic with STOP and coil writes.
  if (!motorController.arm(cmd.generation)) {
    bleManager.sendCommandResult(cmd.id, "cancelled", "superseded by stop");
    return;
  }
  MotionResult result = MotionResult::Done;
  if (cmd.type == 'A') {
    if (!sensorManager.isDistanceValid()) result = MotionResult::SensorInvalid;
    else {
      currentState = AUTONOMOUS;
      navigator.enableAutonomousMode();
    }
  } else {
    navigator.disableAutonomousMode();
    switch (cmd.type) {
      case 'F': currentState = MOVING_FORWARD; result = motorController.moveForward(cmd.value); break;
      case 'B': currentState = MOVING_BACKWARD; result = motorController.moveBackward(cmd.value); break;
      case 'L': currentState = TURNING_LEFT; result = motorController.rotateLeft(cmd.value); break;
      case 'R': currentState = TURNING_RIGHT; result = motorController.rotateRight(cmd.value); break;
    }
    currentState = IDLE;
  }
  if (cmd.generation != motorController.getGeneration() || result == MotionResult::Cancelled) {
    bleManager.sendCommandResult(cmd.id, "cancelled", "stopped during command");
  } else if (result == MotionResult::Done) {
    bleManager.sendCommandResult(cmd.id, "done");
  } else {
    // Failed motion must not be followed by the remainder of a queued program.
    const char* reason = result == MotionResult::Blocked ? "obstacle detected" :
      result == MotionResult::SensorInvalid ? "distance unavailable or stale" : "motion timed out";
    bleManager.stopAll(reason);
    currentState = IDLE;
    bleManager.sendCommandResult(cmd.id, "error", reason);
  }
}

void printSystemStatus() {
  Serial.println("\n========== SYSTEM STATUS ==========");
  Serial.printf("Chip model: %s\n", ESP.getChipModel());
  Serial.printf("CPU frequency: %d MHz\n", ESP.getCpuFreqMHz());
  Serial.printf("Free heap: %d bytes\n", ESP.getFreeHeap());
  Serial.printf("Flash size: %d bytes\n", ESP.getFlashChipSize());
  Serial.printf("BLE address: %s\n", bleManager.getDeviceAddress().c_str());
  Serial.printf("Current state: %d\n", currentState);
  Serial.println("===================================\n");
  
  // Subsystem status
  sensorManager.printSensorStatus();
  navigator.printNavigationStats();
  bleManager.printConnectionStatus();
}

void handleSystemError(const String& error) {
  Serial.printf("SYSTEM ERROR: %s\n", error.c_str());
  
  // Stop all motors
  bleManager.stopAll("system error");
  
  // Disable autonomous mode
  navigator.disableAutonomousMode();
  
  // Send error status if connected
  if (bleManager.isConnected()) {
    bleManager.sendStatus("ERROR: " + error);
  }
  
  // Flash LED or other error indication could go here

  // In a real application, you might want to restart or enter safe mode
}

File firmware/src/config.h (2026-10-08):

#ifndef CONFIG_H
#define CONFIG_H

// BLE Configuration
#define SERVICE_UUID        "12345678-1234-1234-1234-123456789abc"
#define COMMAND_CHAR_UUID   "12345678-1234-1234-1234-123456789abd"
#define SENSOR_CHAR_UUID    "12345678-1234-1234-1234-123456789abe"
#define BLE_DEVICE_NAME     "E-Bug ESP32"

// Pin Definitions
#define TRIG_PIN            5
#define ECHO_PIN            18
// 28BYJ-48 motors through ULN2003 IN1..IN4 (rewire the old STEP/DIR layout).
#define LEFT_IN1_PIN        26
#define LEFT_IN2_PIN        27
#define LEFT_IN3_PIN        25
#define LEFT_IN4_PIN        33
#define RIGHT_IN1_PIN       14
#define RIGHT_IN2_PIN       13
#define RIGHT_IN3_PIN       32
#define RIGHT_IN4_PIN       23
#define SDA_PIN             21
#define SCL_PIN             22

// Motor Configuration: selected 5 V, nominal 1:64 28BYJ-48 + ULN2003.
// Voltage is set by hardware, not firmware. See hardware/power-system.md.
#define STEPS_PER_REV       4096    // nominal half-steps; calibrate the actual gearbox
#define WHEEL_DIAMETER      65      // mm
#define ROBOT_WIDTH         150     // mm
#define HALF_STEP_INTERVAL_US 2000  // conservative 500 half-steps/s
#define DEFAULT_SPEED       HALF_STEP_INTERVAL_US
#define LEFT_MOTOR_INVERT   false   // verify forward direction with wheels raised
#define RIGHT_MOTOR_INVERT  true    // mirrored mounting; verify on hardware

// Command limits (reject out-of-range values, never clamp).
#define MAX_MOVE_DISTANCE_CM    500     // reject runaway forward/backward moves
#define MAX_TURN_ANGLE          360     // degrees

// P1 uses open-loop half-step counting. Runtime CLOOP_ON is explicitly rejected
// until IMU turn-direction, calibration and convergence are validated on hardware.

// Navigation Constants
#define MIN_OBSTACLE_DIST   25      // cm
#define CRITICAL_DISTANCE   15      // cm
#define SCAN_ANGLE_START    -60     // degrees
#define SCAN_ANGLE_END      60      // degrees
#define SCAN_ANGLE_STEP     10      // degrees
#define PATH_MEMORY_SIZE    10

// Task Configuration
#define MOTOR_TASK_STACK    10000
#define SENSOR_TASK_STACK   10000
#define COMM_TASK_STACK     4096
#define COMMAND_QUEUE_SIZE  10

// Timing Constants
#define SENSOR_UPDATE_RATE  60      // ultrasonic trigger period, milliseconds
#define TELEMETRY_UPDATE_RATE 250   // independent of safety sampling
#define DISTANCE_MAX_AGE_MS  250     // older samples cannot authorize forward motion
#define IMU_UPDATE_RATE     10      // milliseconds
#define MOTOR_TASK_DELAY    10      // milliseconds

// Safety Limits
#define ULTRASONIC_TIMEOUT  30000   // microseconds

// Battery Monitoring
// NOTE: Wire the battery through a resistor divider into an ADC1 pin.
// ADC2 pins cannot be used while BLE/Wi-Fi is active. GPIO 34-39 are
// input-only and ideal for analog sensing. Selected pack: Tenergy 31003,
// protected 2S Li-ion, 2200mAh, /3 divider (hardware/power-system.md).
// These endpoints only scale telemetry; they do not provide a low-voltage cutoff.
#define BATTERY_PIN             35      // ADC1_CH7 (input-only, BLE-safe)
#define BATTERY_DIVIDER_RATIO   3.0     // (R1 + R2) / R2 of the divider
#define BATTERY_MAX_VOLTAGE     8.4     // fully charged (2S = 4.2V/cell)
#define BATTERY_MIN_VOLTAGE     6.0     // specified pack endpoint; recharge earlier

#endif // CONFIG_H

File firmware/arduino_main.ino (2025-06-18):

// E-Bug Robot for ESP32 with BLE + Advanced Autonomy
// Combines BLE-controlled commands with smart scanning and path memory
// Components: ESP32, HC-SR04, 2x Stepper Motors (e.g., A4988), MPU6050 IMU

#include <Wire.h>
#include <MPU6050.h>
#include <BLEDevice.h>
#include <BLEUtils.h>
#include <BLEServer.h>
#include <BLE2902.h>
#include <ArduinoJson.h>

// BLE UUIDs
#define SERVICE_UUID        "12345678-1234-1234-1234-123456789abc"
#define COMMAND_CHAR_UUID   "12345678-1234-1234-1234-123456789abd"
#define SENSOR_CHAR_UUID    "12345678-1234-1234-1234-123456789abe"

// Pin Definitions
const int trigPin = 5;
const int echoPin = 18;
const int leftStepPin = 26;
const int leftDirPin = 27;
const int rightStepPin = 14;
const int rightDirPin = 12;
const int leftEnablePin = 25;
const int rightEnablePin = 13;
const int SDA_PIN = 21;
const int SCL_PIN = 22;

// IMU and State Variables
MPU6050 imu;
float yaw = 0.0;
unsigned long lastIMUUpdate = 0;

// BLE Variables
BLEServer* pServer = NULL;
BLECharacteristic* pCommandChar = NULL;
BLECharacteristic* pSensorChar = NULL;
bool deviceConnected = false;
bool oldDeviceConnected = false;

// Motor and Navigation Variables
const int stepsPerRev = 200;
const int wheelDiameter = 65;
const float wheelCircumference = PI * wheelDiameter;
const float robotWidth = 150;
int currentSpeed = 400;
const int minObstacle = 25;
const int criticalDist = 15;

// Path Memory
const int pathMemSize = 10;
float pathMemory[pathMemSize][2];
int pathIndex = 0;

// BLE Command Queue
TaskHandle_t motorTaskHandle = NULL;
TaskHandle_t sensorTaskHandle = NULL;
QueueHandle_t commandQueue;
struct Command { char type; int value; };
bool isAutonomous = false;
float currentDistance = 0;

// BLE Callbacks
class MyServerCallbacks: public BLEServerCallbacks {
  void onConnect(BLEServer* pServer) { deviceConnected = true; }
  void onDisconnect(BLEServer* pServer) { deviceConnected = false; }
};
class CommandCharCallbacks: public BLECharacteristicCallbacks {
  void onWrite(BLECharacteristic *pChar) {
    String val = pChar->getValue().c_str();
    if (val.length()) processCommand(val);
  }
};

void setup() {
  Serial.begin(115200);
  pinMode(trigPin, OUTPUT); pinMode(echoPin, INPUT);
  pinMode(leftStepPin, OUTPUT); pinMode(leftDirPin, OUTPUT);
  pinMode(rightStepPin, OUTPUT); pinMode(rightDirPin, OUTPUT);
  pinMode(leftEnablePin, OUTPUT); pinMode(rightEnablePin, OUTPUT);
  digitalWrite(leftEnablePin, LOW); digitalWrite(rightEnablePin, LOW);
  Wire.begin(SDA_PIN, SCL_PIN);
  imu.initialize();
  initBLE();
  commandQueue = xQueueCreate(10, sizeof(Command));
  for (int i = 0; i < pathMemSize; i++) pathMemory[i][0] = pathMemory[i][1] = 0;
  xTaskCreatePinnedToCore(motorTask, "MotorTask", 10000, NULL, 1, &motorTaskHandle, 1);
  xTaskCreatePinnedToCore(sensorTask, "SensorTask", 10000, NULL, 1, &sensorTaskHandle, 0);
}

void initBLE() {
  BLEDevice::init("E-Bug ESP32");
  pServer = BLEDevice::createServer();
  pServer->setCallbacks(new MyServerCallbacks());
  BLEService *pService = pServer->createService(SERVICE_UUID);
  pCommandChar = pService->createCharacteristic(COMMAND_CHAR_UUID, BLECharacteristic::PROPERTY_WRITE);
  pCommandChar->setCallbacks(new CommandCharCallbacks());
  pSensorChar = pService->createCharacteristic(SENSOR_CHAR_UUID, BLECharacteristic::PROPERTY_NOTIFY);
  pSensorChar->addDescriptor(new BLE2902());
  pService->start(); BLEAdvertising *pAdvertising = BLEDevice::getAdvertising();
  pAdvertising->addServiceUUID(SERVICE_UUID);
  BLEDevice::startAdvertising();
}

void loop() {
  if (!deviceConnected && oldDeviceConnected) { delay(500); pServer->startAdvertising(); oldDeviceConnected = false; }
  if (deviceConnected && !oldDeviceConnected) oldDeviceConnected = true;
  delay(10);
}

void motorTask(void *param) {
  Command cmd;
  while (true) {
    if (xQueueReceive(commandQueue, &cmd, 0) == pdTRUE) executeCommand(cmd);
    if (isAutonomous && deviceConnected) autonomousNavigate();
    vTaskDelay(10 / portTICK_PERIOD_MS);
  }
}

void sensorTask(void *param) {
  while (true) {
    updateYaw(); currentDistance = readDistanceCM();
    broadcastSensorData();
    vTaskDelay(1000 / portTICK_PERIOD_MS);
  }
}

void processCommand(String cmd) {
  cmd.trim(); Command newCmd;
  if (cmd.startsWith("F")) { newCmd.type = 'F'; newCmd.value = cmd.substring(1).toInt(); }
  else if (cmd.startsWith("B")) { newCmd.type = 'B'; newCmd.value = cmd.substring(1).toInt(); }
  else if (cmd.startsWith("L")) { newCmd.type = 'L'; newCmd.value = cmd.substring(1).toInt(); }
  else if (cmd.startsWith("R")) { newCmd.type = 'R'; newCmd.value = cmd.substring(1).toInt(); }
  else if (cmd == "STOP") { newCmd.type = 'S'; newCmd.value = 0; isAutonomous = false; }
  else if (cmd == "AUTO_NAV") { isAutonomous = true; return; }
  xQueueSend(commandQueue, &newCmd, 0);
}

void executeCommand(Command cmd) {
  int steps = (cmd.value * 10.0 / wheelCircumference) * stepsPerRev;
  switch (cmd.type) {
    case 'F': moveForward(steps); break;
    case 'B': moveBackward(steps); break;
    case 'L': rotateRobot(-cmd.value); break;
    case 'R': rotateRobot(cmd.value); break;
    case 'S': stopMoving(); break;
  }
}

void moveForward(int steps) {
  for (int i = 0; i < steps; i++) {
    if (i % 50 == 0 && currentDistance < criticalDist) break;
    digitalWrite(leftDirPin, HIGH); digitalWrite(rightDirPin, HIGH);
    digitalWrite(leftStepPin, HIGH); digitalWrite(rightStepPin, HIGH);
    delayMicroseconds(currentSpeed);
    digitalWrite(leftStepPin, LOW); digitalWrite(rightStepPin, LOW);
    delayMicroseconds(currentSpeed);
  }
}

void moveBackward(int steps) {
  digitalWrite(leftDirPin, LOW); digitalWrite(rightDirPin, LOW);
  for (int i = 0; i < steps; i++) {
    digitalWrite(leftStepPin, HIGH); digitalWrite(rightStepPin, HIGH);
    delayMicroseconds(currentSpeed);
    digitalWrite(leftStepPin, LOW); digitalWrite(rightStepPin, LOW);
    delayMicroseconds(currentSpeed);
  }
}

void rotateRobot(float degrees) {
  float arc = (robotWidth * PI * abs(degrees)) / 360.0;
  int steps = (arc / wheelCircumference) * stepsPerRev;
  digitalWrite(leftDirPin, degrees > 0 ? HIGH : LOW);
  digitalWrite(rightDirPin, degrees > 0 ? LOW : HIGH);
  for (int i = 0; i < steps; i++) {
    digitalWrite(leftStepPin, HIGH); digitalWrite(rightStepPin, HIGH);
    delayMicroseconds(currentSpeed);
    digitalWrite(leftStepPin, LOW); digitalWrite(rightStepPin, LOW);
    delayMicroseconds(currentSpeed);
    updateYaw();
  }
}

void autonomousNavigate() {
  if (currentDistance > minObstacle * 2) moveForward(20);
  else if (currentDistance < criticalDist) {
    stopMoving(); moveBackward(30); rotateRobot(180);
  } else {
    float bestAngle = findBestPath();
    if (bestAngle != -999) rotateRobot(bestAngle);
  }
}
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

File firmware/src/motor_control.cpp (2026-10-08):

#include "motor_control.h"
#include "sensor_manager.h"
#include <cmath>
#include <freertos/task.h>

MotorControl motorController;

namespace {
const int leftPins[] = {LEFT_IN1_PIN, LEFT_IN2_PIN, LEFT_IN3_PIN, LEFT_IN4_PIN};
const int rightPins[] = {RIGHT_IN1_PIN, RIGHT_IN2_PIN, RIGHT_IN3_PIN, RIGHT_IN4_PIN};
// Standard 28BYJ-48 half-step sequence, wired in ULN2003 IN1..IN4 order.
const uint8_t phases[8][4] = {
  {1,0,0,0}, {1,1,0,0}, {0,1,0,0}, {0,1,1,0},
  {0,0,1,0}, {0,0,1,1}, {0,0,0,1}, {1,0,0,1}
};
}

MotorControl::MotorControl() : currentSpeed(DEFAULT_SPEED), stopRequested(true),
  generation(0), leftPhase(0), rightPhase(0), wheelCircumference(PI * WHEEL_DIAMETER) {}

void MotorControl::begin() {
  for (int pin : leftPins) pinMode(pin, OUTPUT);
  for (int pin : rightPins) pinMode(pin, OUTPUT);
  releaseCoils(); // no holding current or movement until an explicit command
}

int MotorControl::distanceToSteps(int distanceCM) {
  return static_cast<int>(lround((distanceCM * 10.0 / wheelCircumference) * STEPS_PER_REV));
}

int MotorControl::angleToSteps(float degrees) {
  const float arc = (ROBOT_WIDTH * PI * fabs(degrees)) / 360.0;
  return static_cast<int>(lround((arc / wheelCircumference) * STEPS_PER_REV));
}

bool MotorControl::stepPair(int leftDirection, int rightDirection) {
  portENTER_CRITICAL(&motionMux);
  if (stopRequested) {
    portEXIT_CRITICAL(&motionMux);
    return false;
  }
  leftPhase = (leftPhase + (LEFT_MOTOR_INVERT ? -leftDirection : leftDirection) + 8) % 8;
  rightPhase = (rightPhase + (RIGHT_MOTOR_INVERT ? -rightDirection : rightDirection) + 8) % 8;
  for (int i = 0; i < 4; ++i) {
    digitalWrite(leftPins[i], phases[leftPhase][i]);
    digitalWrite(rightPins[i], phases[rightPhase][i]);
  }
  portEXIT_CRITICAL(&motionMux);
  return true;
}

MotionResult MotorControl::runSteps(int steps, int leftDirection, int rightDirection, bool checkFront) {
  MotionResult result = MotionResult::Done;
  for (int i = 0; i < steps; ++i) {
    if (isStopPending()) { result = MotionResult::Cancelled; break; }
    // Read a coherent snapshot on every half-step. Rear/side clearance needs supervision.
    if (checkFront) {
      const SensorData data = sensorManager.getSensorData();
      if (!data.distanceValid) { result = MotionResult::SensorInvalid; break; }
      if (data.distance < CRITICAL_DISTANCE) { result = MotionResult::Blocked; break; }
    }
    if (!stepPair(leftDirection, rightDirection)) { result = MotionResult::Cancelled; break; }
    // Yield on every step so long movements do not starve idle/watchdog tasks.
    const TickType_t ticks = pdMS_TO_TICKS((currentSpeed + 999) / 1000);
    vTaskDelay(ticks > 0 ? ticks : 1);
  }
  releaseCoils();
  if (isStopPending()) return MotionResult::Cancelled;
  return result;
}

MotionResult MotorControl::moveForward(int cm) { return moveForwardSteps(distanceToSteps(cm)); }
MotionResult MotorControl::moveBackward(int cm) { return moveBackwardSteps(distanceToSteps(cm)); }
MotionResult MotorControl::moveForwardSteps(int steps) { return runSteps(steps, 1, 1, true); }
MotionResult MotorControl::moveBackwardSteps(int steps) { return runSteps(steps, -1, -1, false); }
MotionResult MotorControl::rotateLeft(float degrees) { return rotateRobot(-degrees); }
MotionResult MotorControl::rotateRight(float degrees) { return rotateRobot(degrees); }
MotionResult MotorControl::rotateRobot(float degrees) {
  return runSteps(angleToSteps(degrees), degrees >= 0 ? 1 : -1, degrees >= 0 ? -1 : 1, false);
}

void MotorControl::releaseCoilsUnlocked() {
  for (int pin : leftPins) digitalWrite(pin, LOW);
  for (int pin : rightPins) digitalWrite(pin, LOW);
}
void MotorControl::releaseCoils() {
  portENTER_CRITICAL(&motionMux);
  releaseCoilsUnlocked();
  portEXIT_CRITICAL(&motionMux);
}
void MotorControl::requestStop() {
  portENTER_CRITICAL(&motionMux);
  stopRequested = true;
  ++generation;
  releaseCoilsUnlocked();
  portEXIT_CRITICAL(&motionMux);
}
bool MotorControl::arm(uint32_t expectedGeneration) {
  portENTER_CRITICAL(&motionMux);
  const bool allowed = expectedGeneration == generation;
  if (allowed) stopRequested = false;
  portEXIT_CRITICAL(&motionMux);
  return allowed;
}
uint32_t MotorControl::getGeneration() const {
  portENTER_CRITICAL(&motionMux);
  uint32_t result = generation;
  portEXIT_CRITICAL(&motionMux);
  return result;
}
bool MotorControl::isStopPending() const {
  portENTER_CRITICAL(&motionMux);
  bool result = stopRequested;
  portEXIT_CRITICAL(&motionMux);
  return result;
}
void MotorControl::stopMoving() { requestStop(); }
void MotorControl::emergencyStop() { requestStop(); }
void MotorControl::setSpeed(int intervalUs) {
  if (intervalUs >= 2000 && intervalUs <= 10000) currentSpeed = intervalUs;
}
int MotorControl::getSpeed() const { return currentSpeed; }
bool MotorControl::checkObstacle() {
  const SensorData data = sensorManager.getSensorData();
  return !data.distanceValid || data.distance < MIN_OBSTACLE_DIST;
}

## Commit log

2026-06-18 fix(firmware): make modular src/ build compile for ESP32
    The PlatformIO src/ target never compiled. Three build-breakers:
    - navigation.h was a byte-for-byte copy of navigation.cpp (no include
    guard, no class declaration, self-include). Replaced with a proper
    header declaring class Navigation.
    - main.cpp defined a manual app_main() that collides with the one the
    Arduino-ESP32 core already provides. Removed it; setup()/loop() are
    invoked by the core.
    - ble_communication.h and sensor_manager.h use Arduino String but never
    included <Arduino.h> (BLE headers only provide std::string). Added the
    include so they compile standalone.
    Verified: `pio run` succeeds (RAM 12.1%, Flash 89.8%),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
    [main.cpp]
2026-06-18 fix(firmware): real battery telemetry, IMU calibration, correct autonomous scan
    - Battery monitoring (#5): replace the hardcoded batteryLevel = 100.0 with
    a real ADC read. New config constants (BATTERY_PIN on ADC1, divider
    ratio, 2S voltage range) drive readBatteryVoltage()/readBatteryPercent(),
    using analogReadMilliVolts() for factory-calibrated accuracy.
    - IMU calibration (#6): calibrateIMU() was implemented but never called, so
    gyro bias was always zero and yaw drifted. Now invoked at boot; corrected
    the misleading "10 seconds" message to ~3s to match the sample count.
    - Autonomous scan (#3): findBestPath() passed absolute angles to the
    RELATIVE rotateRobot(), making the chass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
    [config.h, navigation.cpp, sensor_manager.cpp]
2026-06-18 feat(firmware): clamp command params and make moves interruptible by STOP
    - Bounds-checking (#8): parseCommand() now clamps F/B distance to
    [0, MAX_MOVE_DISTANCE_CM] and L/R angle to [0, MAX_TURN_ANGLE], so a bad
    value like "F99999" can no longer trigger a multi-minute blocking move.
    - Interruptible motion (#7): added a volatile stopRequested flag to
    MotorControl. A BLE "STOP" now calls requestStop() from the BLE task,
    which the step loops in moveForwardSteps/moveBackwardSteps/rotateRobot
    check each iteration and abort. findBestPath() also bails out via
    isStopPending(), so STOP is responsive during autonomous scanning
    instead of waiting ~3s for the sweep to finish. A new explic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
    [ble_communication.cpp, config.h, main.cpp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]
2026-06-18 fix(firmware): serialize HC-SR04 reads across cores with a mutex
    readDistanceCM() is called from both the sensor task (core 0, every 1s) and
    the motor/navigation task (core 1, during autonomous findBestPath/
    getFilteredDistance). Concurrent trigger + pulseIn cycles on the shared
    TRIG/ECHO pins corrupt each other's measurement.
    Added a FreeRTOS mutex created in begin() and taken only inside
    readDistanceCM() (leaf-level, so no nesting or deadlock risk). The hot
    getCurrentDistance() cached read is deliberately left lock-free: a 32-bit
    aligned float read is atomic on Xtensa, and locking it would risk stalling
    the motor step loop behind a 30ms pulseIn timeout.
    IMU/I2C and the sensorData struct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
    [sensor_manager.cpp]
2026-06-18 refactor(firmware): remove dead code, de-magic stack size, archive legacy sketch
    Housekeeping with no behavior change:
    - Remove the unused MotorControl::stepMotor() method (never called; the
    real stepping lives in moveForwardSteps/moveBackwardSteps/rotateRobot).
    - Replace the hardcoded communication-task stack size (4096) with a new
    COMM_TASK_STACK constant in config.h, alongside the other task stacks.
    - Move the legacy single-file Arduino sketch out of the build tree to
    legacy/arduino_main/arduino_main.ino (a valid Arduino sketch folder) so
    it no longer sits next to the modular src/ target. README updated.
    Verified: `pio run` succeeds (RAM 12.2%, Flash 90.5%).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
    [arduino_main.ino, config.h, main.cpp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]
2026-06-18 feat(firmware): persist calibration & speed in NVS, temp-compensated distance
    #13 - Persistence (ESP32 Preferences / NVS, no new dependency):
    - IMU calibration is saved after calibrateIMU() and loaded at boot. First
    boot (or a CALIBRATE command) runs the ~3s routine; later boots load the
    stored offsets and skip it for a fast startup.
    - New CALIBRATE BLE command (type 'C') requests a fresh calibration. The
    request is non-blocking: the sensor task runs the actual calibration via
    serviceRecalibration(), keeping all IMU/I2C access on a single core. The
    command first stops motion and disables autonomy.
    - Motor speed is persisted in setSpeed() and restored in begin().
    #14 - Temperature-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
    [ble_communication.cpp, main.cpp, motor_control.cpp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]
2026-06-18 feat(firmware): experimental closed-loop (IMU) turning, off by default
    Adds optional IMU-feedback turning (#4/#12). DEFAULT OFF, so open-loop
    step-count turning is unchanged and there is no regression risk.
    - New runtime flag closedLoopEnabled (default CLOSED_LOOP_TURN_DEFAULT=0),
    toggled over BLE with CLOOP_ON / CLOOP_OFF (command type 'K').
    - When enabled, rotateRobot() delegates to rotateRobotClosedLoop(): a
    bang-bang controller that steps toward a yaw target until within
    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
2026-06-18 ci: add GitHub Actions workflow (PlatformIO build + flutter analyze)
    Runs on pushes to master and on all pull requests:
    - firmware: installs PlatformIO and runs `pio run` for esp32dev (with a
    cache for ~/.platformio and pip). This is a required gate and would have
    caught the original src/ build-breakers automatically.
    - app: runs `flutter analyze`. Marked continue-on-error for now because the
    app has known pre-existing analyzer issues; flip to a hard gate once the
    mobile-app cleanup lands.
2026-06-22 chore: reorganize repo layout and clean up temp files
    - docs: consolidate curriculum/ and research/ into docs/
    - mobile-app: remove temp analysis/device output files
    - gitignore: block mobile-app temp txt files; ignore local-only paper/
    - README: fix doc links and update project structure diagram
2026-10-08 Align robot firmware, app, and release preparation
    Match 28BYJ-48/ULN2003 hardware, enforce command completion and stop handling, add tested program persistence and BLE lifecycle behavior, and prepare Android packaging.
    Align operating guides with implemented features, preserve historical documents, and record pending physical, CAD, signing, and research acceptance work.

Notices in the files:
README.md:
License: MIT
